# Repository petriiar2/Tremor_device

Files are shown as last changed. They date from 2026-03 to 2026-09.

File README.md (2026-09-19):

# Smart Hand Rehabilitation System — Hardware

> **PCC2 Project | KTH Royal Institute of Technology | MSc Medical Engineering | Stockholm, 2026**  
> *This repository covers only the hardware design, sensor selection, wiring and embedded firmware - the physical core of the system.*
> *Other aspects of the project ( software backend , web application ) are maintained separately and only referenced here for context.*
---

## Table of Contents

- [About the Project](#about-the-project)
- [System Architecture](#system-architecture)
  - [Device Block](#device-block-this-repo)
  - [Computer Block](#computer-block-external-repos)
- [Hardware Design](#hardware-design)
  - [Microcontroller: XIAO Seeed NRF52840](#microcontroller-xiao-seeed-nrf52840)
  - [Sensors](#sensors)
    - [1. Pressure Sensor — ABP-DRRV060MGAA5](#1-pressure-sensor--abp-drrv060mgaa5)
    - [2. EMG Sensor — EMG-LAB](#2-emg-sensor--emg-lab-custom-lab-board)
    - [3. IMU Sensor — LSM6DS3 (on-board NRF52840)](#3-imu-sensor--lsm6ds3-on-board-nrf52840)
  - [Inter-Device Communication](#inter-device-communication)
  - [Design Evolution](#design-evolution)
- [Embedded Firmware](#embedded-firmware)
- [Case Design](#case-design)
- [Device Specifications](#device-specifications)
- [Component List](#component-list)
- [Future Hardware Work](#future-hardware-work)
- [Authors](#authors)
- [License](#license)

## About the Project

Neurological disorders such as stroke, traumatic brain injury, and Parkinson's disease frequently impair hand motor function — manifesting as muscle weakness, tremor, and loss of coordination. Traditional clinical tools like handheld dynamometers capture only peak grip strength, offering an incomplete picture of neuromuscular recovery.

This project is a **low-cost, wearable hand rehabilitation system** that integrates three sensor modalities — pressure, EMG, and IMU — into a portable, Bluetooth-enabled dual-device platform. The system targets two clinical populations:

- **Stroke / Brain Injury** — emphasis on force control assessment (EMG + Pressure)
- **Parkinson's / Tremor-Dominant** — emphasis on movement quality analysis (IMU + Pressure)

The device streams real-time sensor data via Bluetooth Low Energy (BLE) to a companion web application, which guides the patient through rehabilitation exercises, computes clinically meaningful features, and logs sessions for remote clinician review.

> This repository covers the **hardware design**: electrical schematics, sensor integration, embedded firmware, and device prototyping. The web application and signal processing backend are maintained separately and briefly referenced here for context.

---

## System Architecture

The system is split into two main blocks.

### Device Block (this repo)

Two independent wearable units communicate with each other and relay all data to the computer:

```
[Forearm Unit]                         [Wrist Unit]
 ├─ NRF52840 board (Micro 1)            ├─ NRF52840 board (Micro 2)
 ├─ EMG-LAB sensor (analog, 3.3V, D0)   ├─ Pressure sensor ABP-DRRV060MGAA5 (D0)
 ├─ Li-Po 5V battery (JST)              ├─ On-board IMU LSM6DS3 (3-axis accel + gyro)
 └─ USB-B connector (UART TX/RX)        ├─ Li-Po 5V battery (JST)
                                        └─ USB-A connector (UART TX/RX)
                 │                                   │  │
                 └──────────── UART ─────────────────┘  │
                                                        │
                                                   BLE (2.4 GHz)
                                                        │
                                                    [Computer]
```

The forearm unit (Micro 1) collects EMG data, applies preliminary digital filtering on-chip, and forwards the processed samples to the wrist unit over a UART serial link. The wrist unit (Micro 2) acts as the aggregation node — it samples EMG, IMU, and pressure data and transmits everything to the computer over Bluetooth using the Nordic UART Service (NUS).

### Computer Block (external repos)

- **FastAPI backend** — receives BLE data via WebSocket, runs the signal processing and feature extraction pipeline
- **Web application** — real-time sensor visualization, exercise guidance, session logging, and longitudinal progress tracking
- **ML pipeline** — SVM state classifier pre-trained on public datasets + centroid distance longitudinal progress tracker (kNN planned as a later extension)

---

## Hardware Design

### Microcontroller: XIAO Seeed NRF52840

Both units are built around the **NRF52840** board (NRF52 family). Key properties that motivated this choice:

| Feature | Value |
|---|---|
| Processor | 32-bit ARM Cortex-M4 with FPU |
| Clock speed | 64 MHz |
| Flash | 2 MB |
| BLE | Built-in (2.4 GHz) |
| IMU | Built-in LSM6DS3 (3-axis accelerometer + gyroscope) |
| I/O | Digital + analog pins, I²C, UART |
| Power | Onboard Li-Po charging module (5V input via JST) |
| Size | Compact form factor |

All analog signal processing (filtering, ADC) happens directly on the board, eliminating the need for external op-amp circuits. This is a deliberate departure from the original design (see [Design Evolution](#design-evolution) below).

---

### Sensors

#### 1. Pressure Sensor — ABP-DRRV060MGAA5

**Purpose:** Measures grip force during exercises. Connected via a plastic tube to a rubber bulb held in the patient's hand.

| Property | Value |
|---|---|
| Supply voltage | 3.3 V |
| Output | Analog (connected to pin `D0` on wrist unit) |
| Principle | Piezoresistive — silicon diaphragm deforms under pressure, resistance change → analog voltage |
| Placement | On-board the wrist device; tube routed to patient's palm |

**Why this sensor?** A commercial dynamometer capable of real-time wireless data transmission was the original target, but budget constraints led to this pressure sensor solution. Its output voltage scales linearly with applied pressure, so it reliably captures the force waveform over time, enabling extraction of features beyond simple peak force. Unlike a rigid load cell, it integrates into a deformable object that minimizes wrist loading during tremor measurement.

**Signal preprocessing:** Butterworth low-pass filter at 20 Hz cutoff to remove high-frequency noise from hand vibrations. Optional DC baseline correction when the hand is at rest.

**Extracted features:**

| Feature | Formula / Description |
|---|---|
| Maximum Voluntary Contraction (MVC) | Peak force during a maximal squeeze |
| Rate of Force Development (RFD) | `dF/dt` — slope of the force-time curve |
| Fatigue Index | `(F_initial − F_final) / F_initial` |
| Force Variability (CV) | `SD / Mean Force` — coefficient of variation during submaximal holds |
| Tremor amplitude | Force oscillation amplitude during steady holds (Parkinson group) |
| Spectral power in tremor band | PSD integrated over 4–12 Hz |

---

#### 2. EMG Sensor — EMG-LAB (custom lab board)

**Purpose:** Measures electrical activity of the flexor digitorum superficialis muscle to assess neuromuscular activation, fatigue, and tremor modulation.

| Property | Value |
|---|---|
| Supply voltage | 3.3 V |
| Output | Analog (connected to pin `D0` on forearm unit) |
| Electrode configuration | Both measurement electrodes embedded directly on board; virtual ground reference on-board |
| Placement | Inner forearm, fixed with silver chloride gel electrodes |

**Why this sensor?** The previous design used a Muscle Sensor V3.0, which required a ±9 V bipolar supply (two 9 V batteries = 90 g of bulk). The EMG-LAB sensor runs at 3.3 V from the same Li-Po battery powering the board, dramatically reducing weight and complexity.

> ⚠️ The EMG-LAB sensor was borrowed from a previous laboratory project and must be returned after completion. The sensor is mounted in a removable socket soldered onto the forearm PCB.

**Electrode placement:** Electrodes must be aligned along the muscle fibers of the flexor digitorum superficialis, spaced ≤ 2 cm apart. Good-quality silver chloride gel electrodes are required to minimize skin-electrode impedance.

**Signal preprocessing (two-stage pipeline):**

*On-chip (NRF52840, Stage 1):*
- DC offset removal — an exponential moving average estimates and subtracts the DC component to center the signal around zero
- Digital notch filter at 50 Hz — a second-order IIR filter removes power-line interference
- Lightweight IIR band-pass filter (20–450 Hz) — attenuates motion artifacts and high-frequency sensor noise while preserving the physiological EMG band

*Offline in Python (backend, Stage 2):*
- Higher-order Butterworth band-pass 20–450 Hz — sharper cutoff and better stopband attenuation
- Full-wave rectification
- Moving RMS window — generates smooth muscle activation envelope

**Extracted features:**

| Feature | Formula / Description |
|---|---|
| EMG RMS | `sqrt(1/N * Σ e²_i)` — overall muscle activation level |
| Median Frequency Shift | Change in spectral median between first and second half of contraction — fatigue indicator |
| Tremor Band Power | PSD of EMG envelope integrated over 2–12 Hz |
| Peak Tremor Frequency | `argmax PSD` over [2, 12] Hz — identifies dominant tremor frequency |
| Electromechanical Delay (EMD) | `t_force_onset − t_EMG_onset` — neuromuscular transmission efficiency |

---

#### 3. IMU Sensor — LSM6DS3 (on-board NRF52840)

**Purpose:** Measures linear acceleration and angular velocity in 3 axes to quantify hand tremor, orientation stability, and movement quality.

| Property | Value |
|---|---|
| Model | LSM6DS3 (integrated on the NRF52840 board) |
| Type | 3-axis accelerometer + 3-axis gyroscope (MEMS) |
| Interface | I²C at address `0x6A` |
| Configuration | ±2 g accelerometer, ±250 °/s gyroscope, 104 Hz ODR (decimated to 25 Hz) |
| Supply | Powered by the NRF52840 board (no extra wiring) |
| Placement | Wrist unit, outer side of the hand |

**Signal preprocessing:**
- Butterworth low-pass filter at 20 Hz cutoff (accelerometer + gyroscope)
- Sensor fusion (accelerometer + gyroscope) for accurate orientation estimation and drift reduction
- FFT / PSD for frequency-domain tremor analysis

**Clinically relevant frequency bands:**

| Band | Range | Meaning |
|---|---|---|
| Physiological tremor | 8–12 Hz | Normal, non-pathological oscillations |
| Parkinson's rest tremor | 4–6 Hz | Pathological resting tremor |
| Essential tremor | 5–12 Hz | Postural or action tremor |
| Voluntary / postural | < 4 Hz | Excluded from tremor analysis |

**Extracted features:**

| Feature | Formula / Description |
|---|---|
| Tremor Power (4–12 Hz) | `Σ PSD(a_mag)` over 4–12 Hz |
| Tremor Frequency | `argmax PSD(a_mag)` over [4, 12] Hz |
| Orientation Stability | `Var(θ)` during hold phase |
| Range of Motion (ROM) | `θ_max − θ_min` during grip/dynamic tasks |
| Hold Stability | `SD(ω_mag)` during plateau phase |
| Drift Rate | `(θ_end − θ_start) / t_hold` |

---

### Inter-Device Communication

The two boards communicate via **UART** over pins `D6`–`D7` at 115200 baud, routed through an external USB cable (USB-A on the wrist unit, USB-B on the forearm unit). UART was chosen because it is a digital interface — it introduces zero noise into the data, and all analog signal paths are kept as short as possible within each unit.

The forearm unit (Micro 1) transmits each filtered EMG value to the wrist unit in the ASCII format `E,<value>\n`. Its BLE radio remains disabled to conserve power.

Bluetooth transmission is intentionally implemented only from the **wrist unit** (Micro 2) to minimize electromagnetic interference with the sensitive EMG module on the forearm unit. Two interference mechanisms were identified and mitigated:

1. The BLE 2.4 GHz carrier — kept physically separated from the EMG analog path
2. Uneven BLE power consumption — current spikes during active transmission can cause voltage supply fluctuations that corrupt EMG readings

---

### Design Evolution

#### Why Moved Away from the Original Design

> The old single-unit schematic is preserved for reference:
<p align="center">
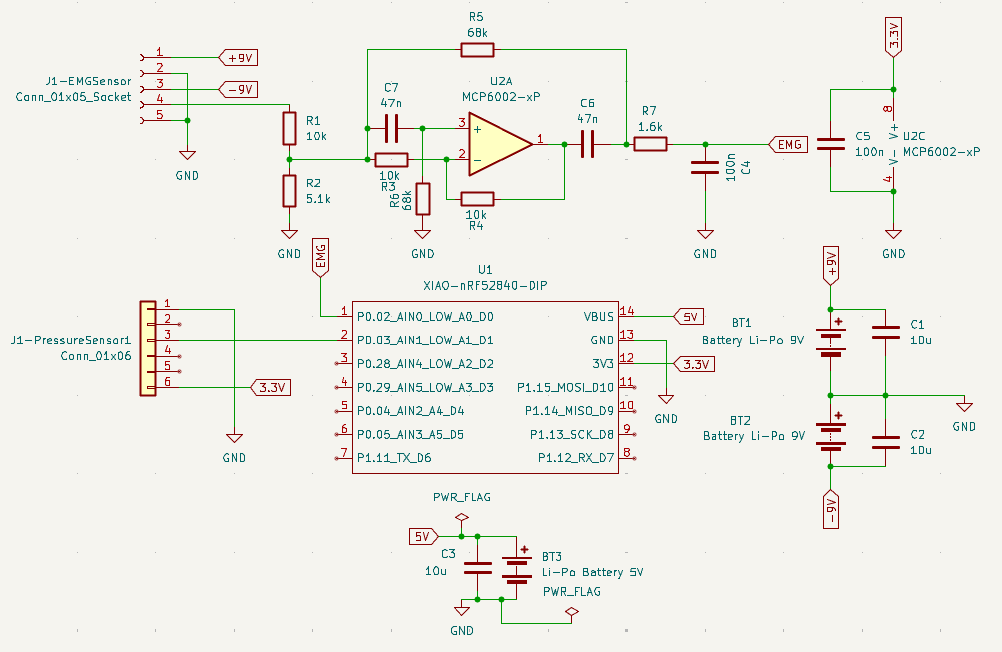
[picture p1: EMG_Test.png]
  
</p>

The first prototype used a **Muscle Sensor V3.0** EMG sensor with an analog filter cascade (band-stop at 50 Hz + low-pass at 1000 Hz). The original single-unit board integrated all sensors (pressure, EMG, IMU) on one wrist-worn device powered by two 9 V batteries. Two critical problems emerged:

**Battery problem:** The Muscle Sensor V3.0 requires a ±9 V bipolar supply. Generating this from two 9 V batteries (each 45 g) mounted on the wrist added significant mass — enough to mechanically affect tremor measurements and distort baseline muscle load:

```
Greater load → higher permanent muscle strain → signal offset relative to unloaded baseline
```

Because the NRF52 board accepts a maximum of 3.3 V on its pins, the bipolar supply was stepped down with a voltage divider (`R1 = 10 kΩ`, `R2 = 5.1 kΩ` → ≈ 3.04 V). A band-stop filter (MCP6002 op-amp, `C7 = 47 nF`, `R6 = 68 kΩ`) targeted 50 Hz mains (≈ 49.7 Hz), and a low-pass stage (`R7 = 1.6 kΩ`, `C = 100 nF`) cut noise above ≈ 995 Hz.

**Analog filtering problem:** Component availability in the lab was limited; the exact resistor-capacitor values for the target filter frequencies were not always obtainable. Compromise values resulted in poorly attenuated noise, requiring additional digital post-processing anyway. Since digital filtering on the NRF52840 is more precise and flexible than any analog cascade achievable with available parts, analog filtering was abandoned entirely.

#### Current Design Improvements

<p align="center">
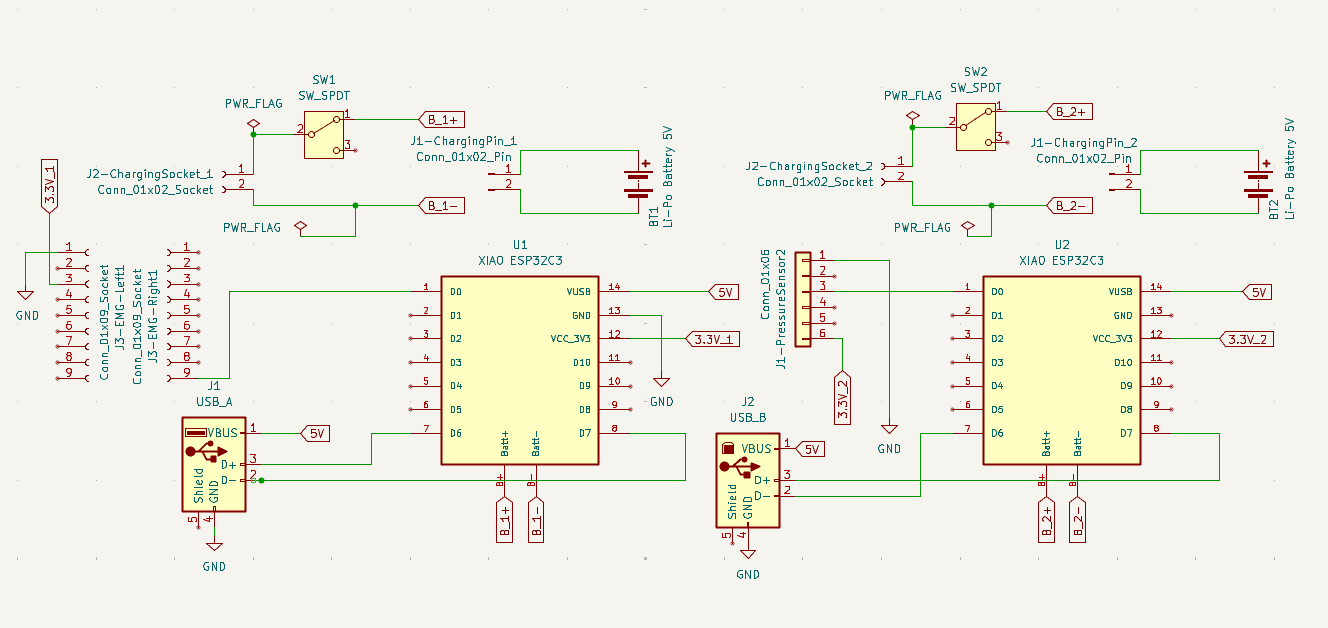
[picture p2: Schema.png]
  
</p>

The new EMG-LAB sensor has both electrodes embedded directly on the board. To minimize wire length between the sensor and the microcontroller (reducing noise), the board and sensor are placed on the inner forearm. Since tremor must still be measured at the wrist, the original single device was split into two independent units: one on the wrist and one on the inner forearm.

| Aspect | Old Design | Current Design |
|---|---|---|
| EMG sensor | Muscle Sensor V3.0 | EMG-LAB (3.3V, on-board electrodes) |
| Power supply | 2× 9V batteries (90g) | 2× Li-Po 5V (10g each) |
| Analog filtering | Band-stop + low-pass RC circuits | Removed — fully digital |
| Physical form | Single unit on wrist | Two units: forearm (EMG) + wrist (IMU/Pressure) |
| Weight (forearm) | — | 21 g (27 g with battery) |
| Weight (wrist) | — | 16 g (35 g with battery) |
| IMU placement | Wrist | Wrist (enables future forearm tremor localization) |

The two boards each have their own 5 V Li-Po battery on a 2-pin JST connector, so every unit operates fully independently, both operationally and energetically. Dedicated slide switches allow each device to be turned on independently and shut down in a controlled manner.

PCBs were designed for both devices according to the tested prototypes and their circuits. Due to the limited budget and capabilities of the university equipment, PCB fabrication was abandoned in favor of perfboard prototypes trimmed to fit the components — but the completed board designs are documented here as the intended production form.

**PCB layouts (2D):**
<p align="center">
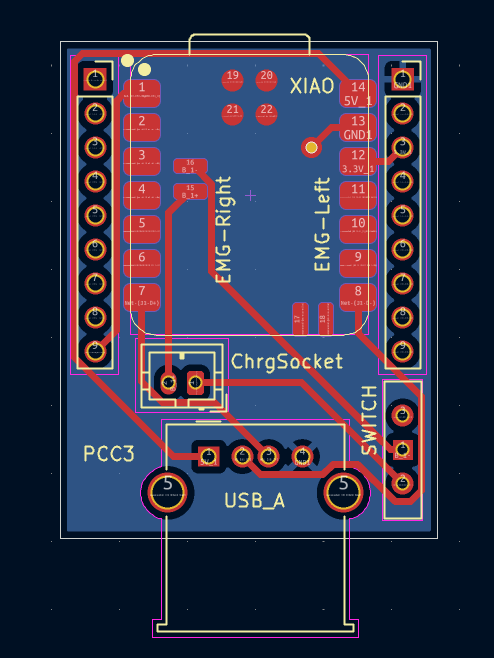
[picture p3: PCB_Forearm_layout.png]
  
  &nbsp;
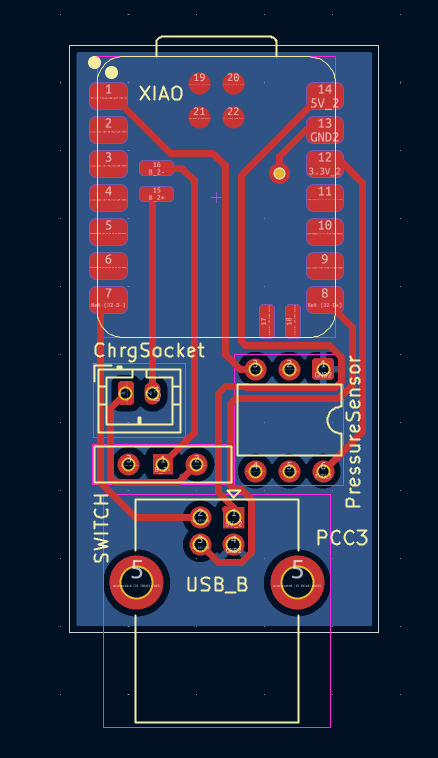
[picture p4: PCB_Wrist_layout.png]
  
</p>
<p align="center"><i>(left) Forearm device — EMG sensor board &nbsp;•&nbsp; (right) Wrist device — pressure sensor board</i></p>

**PCB 3D renders:**
<p align="center">
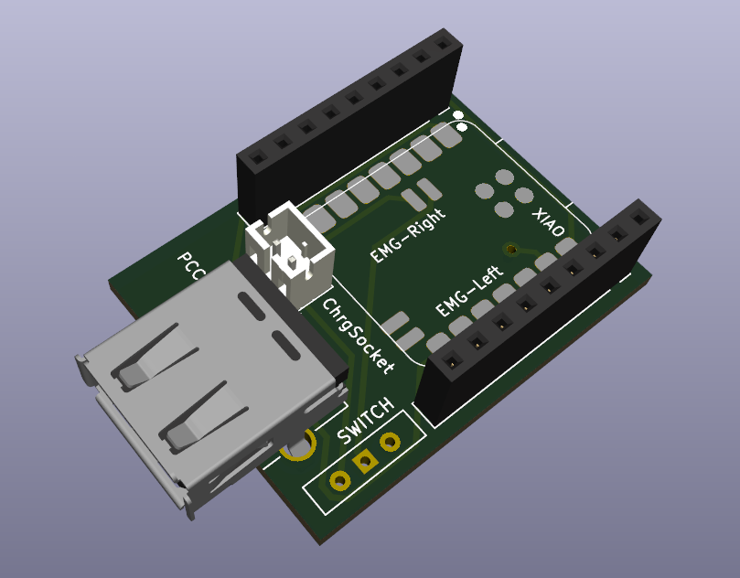
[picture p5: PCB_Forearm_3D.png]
  
  &nbsp;
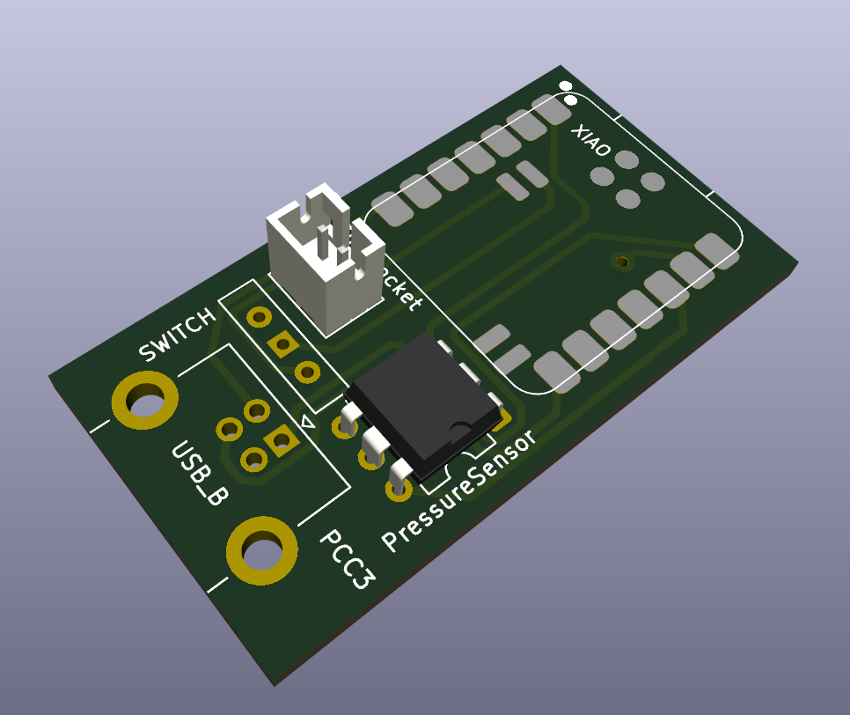
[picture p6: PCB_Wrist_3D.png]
  
</p>
<p align="center"><i>(left) Forearm device 3D view &nbsp;•&nbsp; (right) Wrist device 3D view</i></p>

Image of the forearm device
<p align="center">
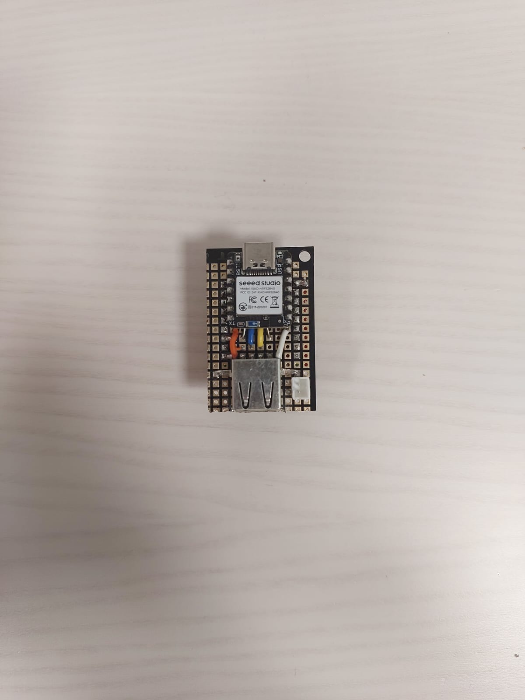
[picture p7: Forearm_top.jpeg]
  
  &nbsp;
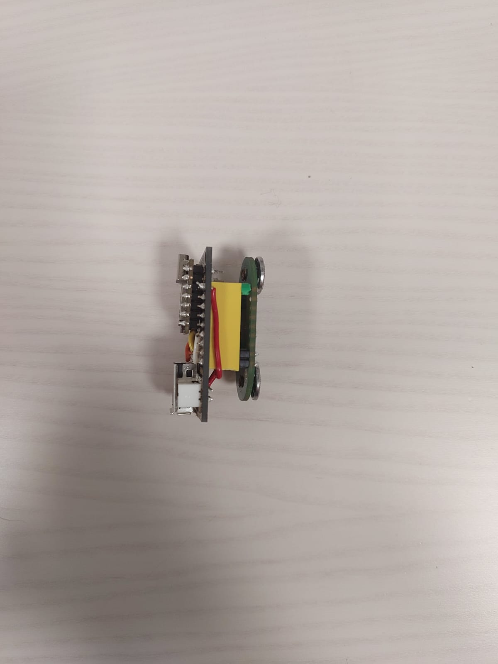
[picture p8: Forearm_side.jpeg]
  
</p>

Image of the wrist device and the general view of the system
<p align="center">
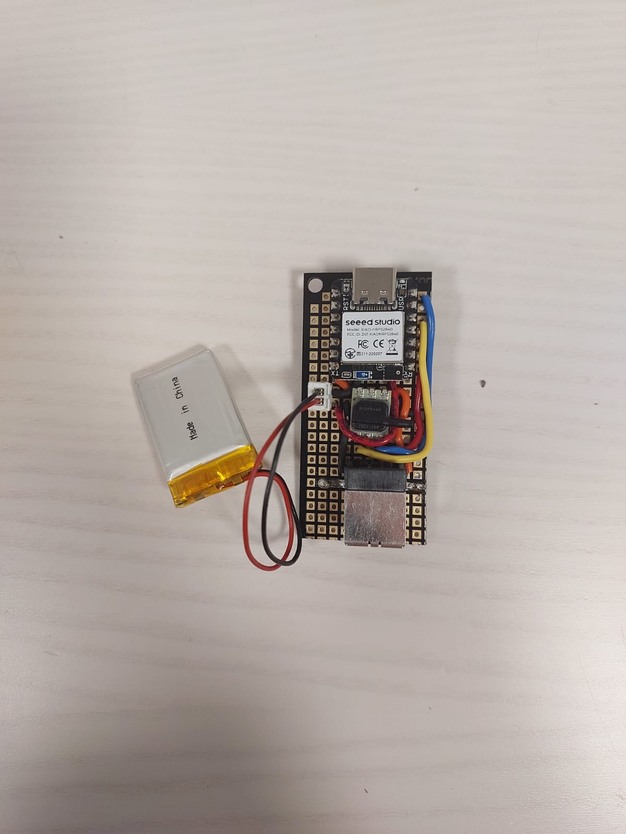
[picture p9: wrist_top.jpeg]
  
  &nbsp;
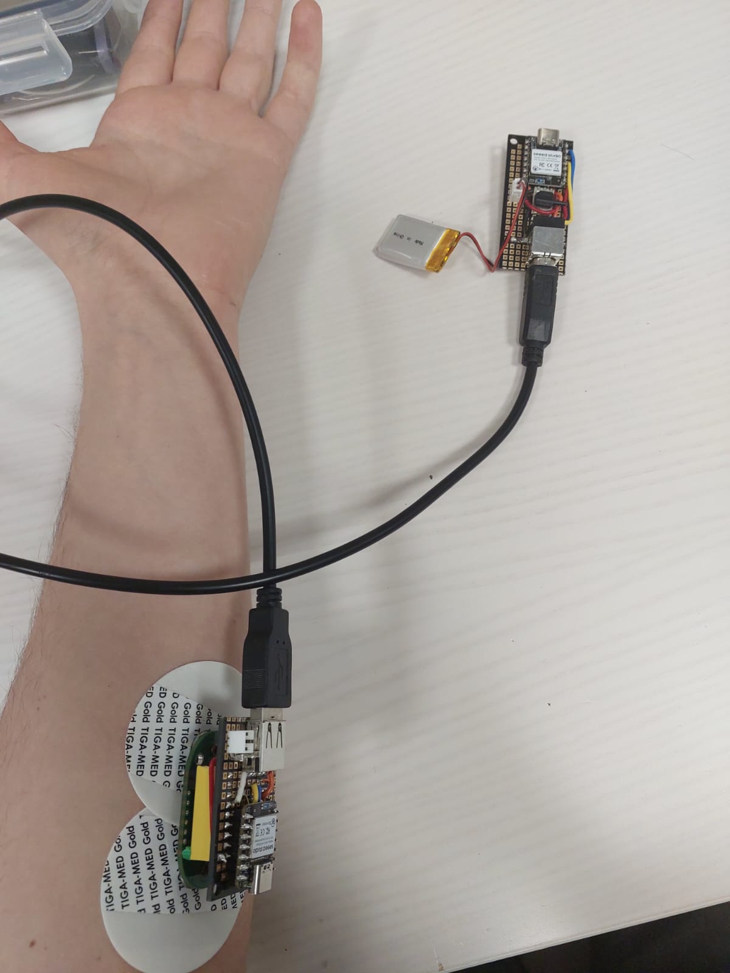
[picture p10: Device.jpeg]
  
</p>

---

## Embedded Firmware

Both microcontrollers run identical **40 ms timing loops**, giving a system-wide sampling rate of **25 Hz**. This rate provides a ~56% margin above the Nyquist minimum for the 4–12 Hz tremor band, lets the frame fit within the negotiated BLE MTU, and allows the MCU to deep-sleep between transmissions (battery life > 8 h continuous).

**Micro 1 (forearm — EMG):** samples EMG at 25 Hz, runs the on-device two-stage preprocessing (DC offset removal + 50 Hz IIR notch + 20–450 Hz band-pass), and pushes each value over UART.

**Micro 2 (wrist — aggregation + BLE):** three concurrent tasks —
- **Pressure:** 12-bit ADC reading (0–4095) from `D0`, normalized to 8-bit (÷16)
- **IMU:** LSM6DS3 over I²C `0x6A`, `CTRL1_XL`/`CTRL2_G = 0x60`, decimated to 25 Hz
- **EMG reception:** character-by-character UART parser on the `E,<value>\n` stream

Every 40 ms the aggregated values are packed into a single comma-separated ASCII frame and sent via the Nordic UART Service (NUS):

```
F,<frame_id>,<pressure>,<emg>,<ax>,<ay>,<az>,<gx>,<gy>,<gz>\n
```

Frames are ~35–40 bytes. Integrity is checked by counting comma separators (9 expected); malformed frames are discarded. A **247-byte MTU** is requested at connection so the full frame fits in one BLE packet without fragmentation, though the system still works if a lower MTU is negotiated. Transmission is fire-and-forget (no retransmission); frame-ID gaps flag packet loss, which stays under 1% and does not affect clinical assessment.

---

## Case Design

A protective case is required for safe patient use: it must isolate the patient from the circuit elements and hold the board and battery cells together as one unit. Given the constraints of the available tools and 3D printer, each case is built around a **rigid printed substrate**, complemented by a soft outer layer:

- **Forearm (arm) device** — the rigid substrate is paired with a soft-plastic cover of a similar shape.
- **Wrist device** — the rigid substrate is fixed inside a sports band through purpose-designed eyelets.

**Case substrates (3D design):**
<p align="center">
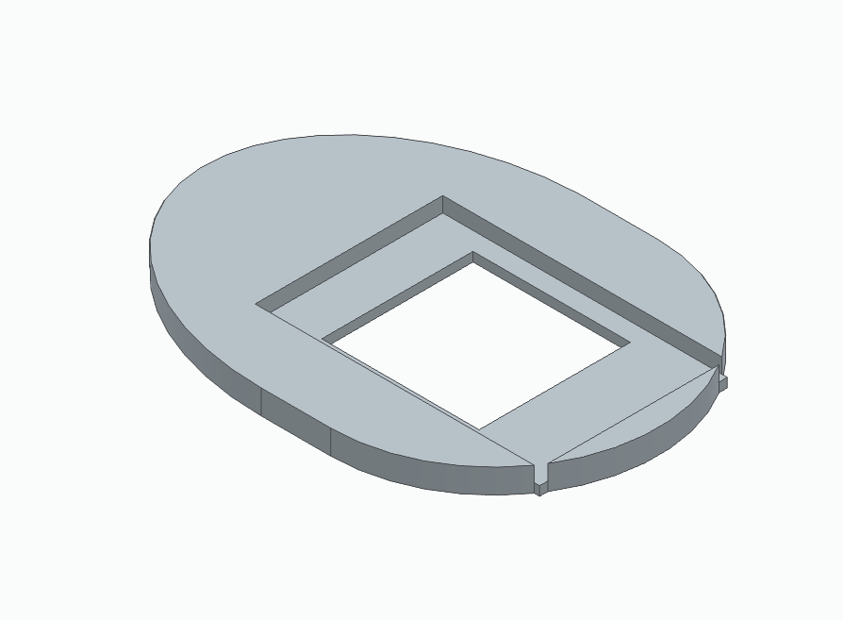
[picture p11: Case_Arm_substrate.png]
  
  &nbsp;
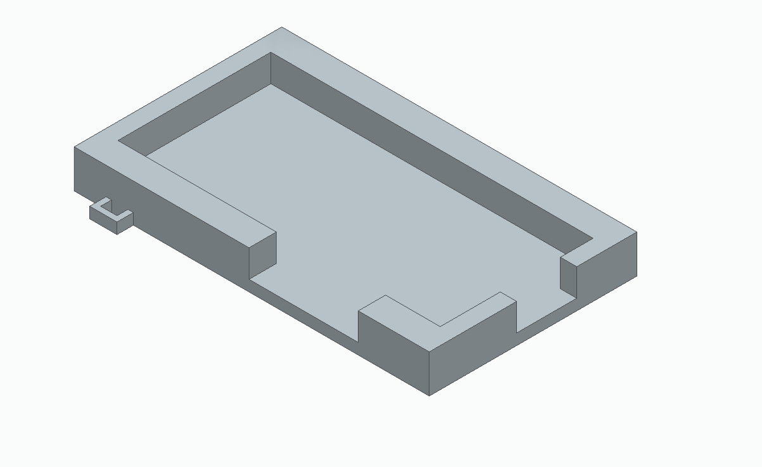
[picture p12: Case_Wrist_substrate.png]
  
</p>
<p align="center"><i>(left) Arm device substrate &nbsp;•&nbsp; (right) Wrist device substrate</i></p>

**Assembled devices in their cases:**
<p align="center">
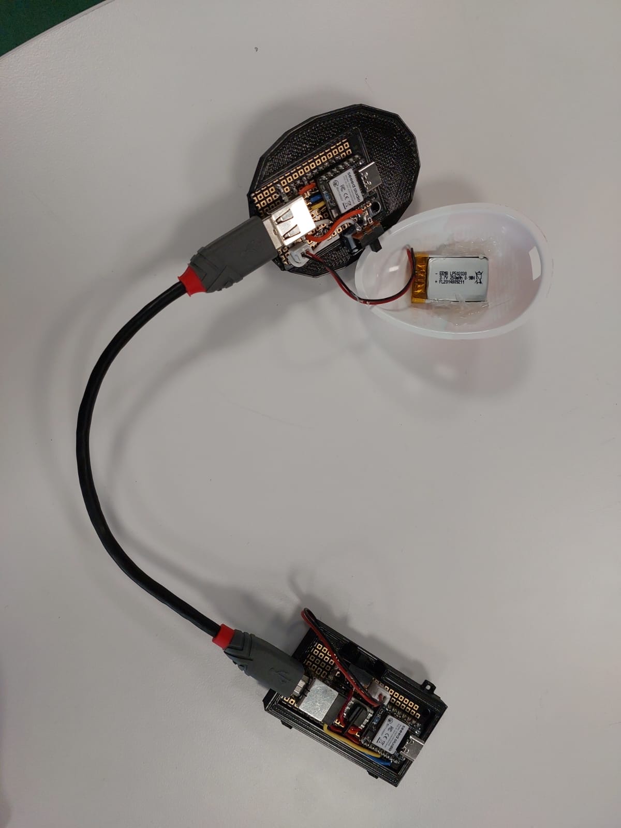
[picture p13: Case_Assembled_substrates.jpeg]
  
  &nbsp;
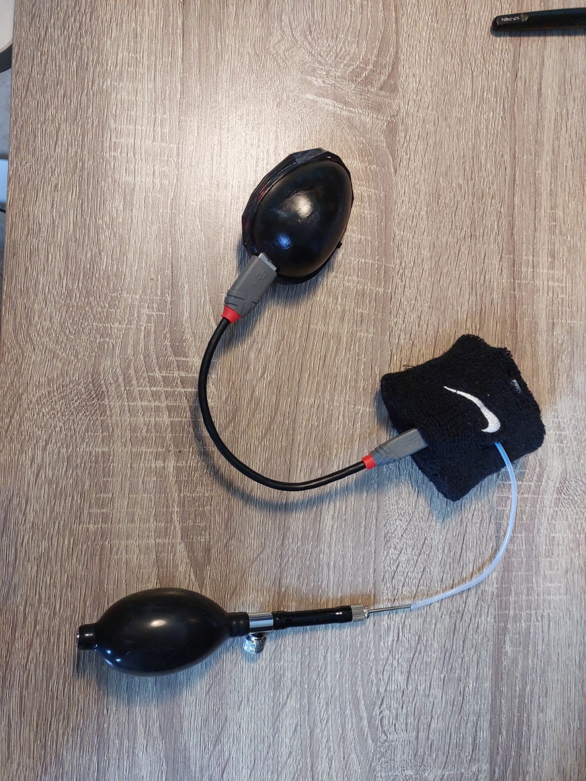
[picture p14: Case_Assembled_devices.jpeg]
  
</p>
<p align="center"><i>(left) Assembled substrates &nbsp;•&nbsp; (right) Fully assembled devices with bulb and strap</i></p>

**Device in use:**
<p align="center">
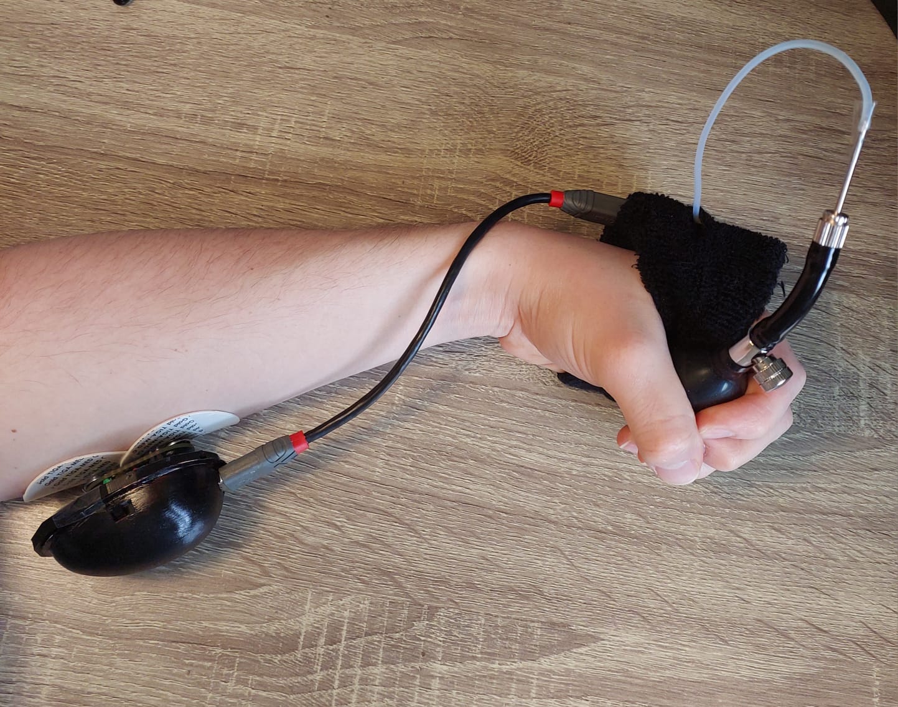
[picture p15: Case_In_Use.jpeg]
  
</p>
<p align="center"><i>General view of the system worn on the hand and forearm</i></p>

**Known limitations of the current case:**
- The university printer could not produce the complex mechanical elements originally planned to hold the arm-device cap, so those were dropped.
- The main fasteners are currently weakly adhesive elements, which do not provide a sufficiently stable fit. Stronger *permanent* fastening is not acceptable, because the device must remain accessible for programming and configuration — a removable but firmer mechanism is needed.
- The EMG-sensor clip mechanism is particularly weak; its fastenings have loosened through wear, and since the sensor is on loan it cannot be permanently re-fitted.

---

## Device Specifications

### Forearm Unit
- **Weight:** 21 g (27 g including battery)
- **Dimensions:** 3.0 × 4.6 × 2.2 cm
- **Mounting:** Silver chloride gel electrodes adhered directly to the inner forearm skin
- **Battery:** 300 mAh Li-Po, 3.7–5 V, rechargeable via JST connector

### Wrist Unit
- **Weight:** 16 g (35 g including battery)
- **Dimensions:** 2.7 × 5.8 × 1.4 cm
- **Mounting:** Sports fabric strap on the outer wrist
- **Battery:** 300 mAh Li-Po, 3.7–5 V, rechargeable via JST connector

> For reference, a single 9 V battery weighs 45 g — illustrating the significant weight reduction achieved by moving to compact Li-Po cells.

---

## Component List

| Component | Model / Type | Role |
|---|---|---|
| Main board ×2 | NRF52840 (NRF52 family) | Core controller, BLE, IMU |
| IMU | LSM6DS3 (on-board, 3-axis accel + gyro) | Motion and tremor sensing |
| Pressure sensor | ABP-DRRV060MGAA5 | Grip force measurement |
| EMG sensor | EMG-LAB (lab-sourced) | Muscle activation measurement |
| Forearm connector | USB-B (4-pin) | UART inter-device link |
| Wrist connector | USB-A (4-pin) | UART inter-device link |
| Batteries ×2 | 3.7–5 V Li-Po, 300 mAh | Board power supply |
| Electrode pads | Silver chloride gel | EMG signal acquisition |

---

## Future Hardware Work

**Enclosure & mechanical**
- **Stronger case fastening:** replace the weak adhesive fasteners with a firmer *removable* mechanism (e.g. clothespin-style clips) or use more advanced printing methods, while keeping the device accessible for programming and configuration.
- **EMG sensor clip:** the borrowed EMG-LAB mounting clip has loosened with wear and needs a proper replacement holder.
- **Manufactured PCBs:** fabricate the documented board designs instead of perfboard prototypes once budget/equipment allow.

**Power**
- **Power switch:** slide switches are present per unit; a unified power scheme is desirable.
- **Unified charging:** single charging port / switch for both units instead of two separate JST connectors.

**Sensing**
- **Extended sensor coverage:** additional IMU unit on the forearm to localize tremor by segment.
- **Analog filter revisit:** at a later stage, when minimizing acquisition latency becomes critical, a minimal analog pre-filter stage may be reintroduced.

---

## Authors

This project was developed as part of a university course project.

- **Iaroslav Petrishchev** — Hardware design, electrical schematics, component selection and procurement, device assembly and testing, case design *(this repository)*
- **Naya Nasr** [LinkedIn](https://www.linkedin.com/in/nasrnaya/)  — NRF52 sensor programming, data acquisition firmware, web application, machine learning pipeline
- **Lucía Pérez Sáez** [LinkedIn]( https://www.linkedin.com/in/lucia-perez-saez/)  — Exercise protocols, signal processing design, backend integration, FSM and WebSocket logic

---

## License

To be determined.

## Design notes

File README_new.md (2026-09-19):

# Smart Hand Rehabilitation System — Hardware

> ⚠️ **This repository is under active development.** Hardware schematics, firmware code, and documentation will be updated continuously as the project evolves.
> 
> **PCC2 Project | KTH Royal Institute of Technology | MSc Medical Engineering | Stockholm, 2026**  
> *This repository covers only the hardware design, sensor selection, wiring and embedded firmware - the physical core of the system.*
> *Other aspects of the project ( software backend , web application ) are maintained separately and only referenced here for context.*
---

## Table of Contents

- [About the Project](#about-the-project)
- [System Architecture](#system-architecture)
  - [Device Block](#device-block-this-repo)
  - [Computer Block](#computer-block-external-repos)
- [Hardware Design](#hardware-design)
  - [Microcontroller: XIAO Seeed NRF52840](#microcontroller-xiao-seeed-nrf52840)
- [Sensors](#sensors)
  - [1. Pressure Sensor — ABP-DRRV060MGAA5](#1-pressure-sensor--abp-drrv060mgaa5)
  - [2. EMG Sensor — EMG-LAB](#2-emg-sensor--emg-lab-custom-lab-board)
  - [3. IMU Sensor — LSM6DS3 (on-board NRF52840)](#3-imu-sensor--lsm6ds3-on-board-nrf52840)
- [Inter-Device Communication](#inter-device-communication)
- [Embedded Firmware](#embedded-firmware)
- [Design Evolution](#design-evolution)
- [Device Specifications](#device-specifications)
- [Component List](#component-list)
- [Future Hardware Work](#future-hardware-work)
- [Authors](#authors)
- [License](#license)

## About the Project

Neurological disorders such as stroke, traumatic brain injury, and Parkinson's disease frequently impair hand motor function — manifesting as muscle weakness, tremor, and loss of coordination. Traditional clinical tools like handheld dynamometers capture only peak grip strength, offering an incomplete picture of neuromuscular recovery.

This project is a **low-cost, wearable hand rehabilitation system** that integrates three sensor modalities — pressure, EMG, and IMU — into a portable, Bluetooth-enabled dual-device platform. The system targets two clinical populations:

- **Stroke / Brain Injury** — emphasis on force control assessment (EMG + Pressure)
- **Parkinson's / Tremor-Dominant** — emphasis on movement quality analysis (IMU + Pressure)

The device streams real-time sensor data via Bluetooth Low Energy (BLE) to a companion web application, which guides the patient through rehabilitation exercises, computes clinically meaningful features, and logs sessions for remote clinician review.

> This repository covers the **hardware design**: electrical schematics, sensor integration, embedded firmware, and device prototyping. The web application and signal processing backend are maintained separately and briefly referenced here for context.

---

## System Architecture

The system is split into two main blocks.

### Device Block (this repo)

Two independent wearable units communicate with each other and relay all data to the computer:

```
[Forearm Unit]                         [Wrist Unit]
 ├─ NRF52840 board (Micro 1)            ├─ NRF52840 board (Micro 2)
 ├─ EMG-LAB sensor (analog, 3.3V, D0)   ├─ Pressure sensor ABP-DRRV060MGAA5 (D0)
 ├─ Li-Po 5V battery (JST)              ├─ On-board IMU LSM6DS3 (3-axis accel + gyro)
 └─ USB-B connector (UART TX/RX)        ├─ Li-Po 5V battery (JST)
                                        └─ USB-A connector (UART TX/RX)
                 │                                   │  │
                 └──────────── UART ─────────────────┘  │
                                                        │
                                                   BLE (2.4 GHz)
                                                        │
                                                    [Computer]
```

The forearm unit (Micro 1) collects EMG data, applies preliminary digital filtering on-chip, and forwards the processed samples to the wrist unit over a UART serial link. The wrist unit (Micro 2) acts as the aggregation node — it samples EMG, IMU, and pressure data and transmits everything to the computer over Bluetooth using the Nordic UART Service (NUS).

### Computer Block (external repos)

- **FastAPI backend** — receives BLE data via WebSocket, runs the signal processing and feature extraction pipeline
- **Web application** — real-time sensor visualization, exercise guidance, session logging, and longitudinal progress tracking
- **ML pipeline** — SVM state classifier pre-trained on public datasets + centroid distance longitudinal progress tracker (kNN planned as a later extension)

---

## Hardware Design

### Microcontroller: XIAO Seeed NRF52840

Both units are built around the **NRF52840** board (NRF52 family). Key properties that motivated this choice:

| Feature | Value |
|---|---|
| Processor | 32-bit ARM Cortex-M4 with FPU |
| Clock speed | 64 MHz |
| Flash | 2 MB |
| BLE | Built-in (2.4 GHz) |
| IMU | Built-in LSM6DS3 (3-axis accelerometer + gyroscope) |
| I/O | Digital + analog pins, I²C, UART |
| Power | Onboard Li-Po charging module (5V input via JST) |
| Size | Compact form factor |

All analog signal processing (filtering, ADC) happens directly on the board, eliminating the need for external op-amp circuits. This is a deliberate departure from the original design (see [Design Evolution](#design-evolution) below).

---

## Sensors

### 1. Pressure Sensor — ABP-DRRV060MGAA5

**Purpose:** Measures grip force during exercises. Connected via a plastic tube to a rubber bulb held in the patient's hand.

| Property | Value |
|---|---|
| Supply voltage | 3.3 V |
| Output | Analog (connected to pin `D0` on wrist unit) |
| Principle | Piezoresistive — silicon diaphragm deforms under pressure, resistance change → analog voltage |
| Placement | On-board the wrist device; tube routed to patient's palm |

**Why this sensor?** A commercial dynamometer capable of real-time wireless data transmission was the original target, but budget constraints led to this pressure sensor solution. Its output voltage scales linearly with applied pressure, so it reliably captures the force waveform over time, enabling extraction of features beyond simple peak force. Unlike a rigid load cell, it integrates into a deformable object that minimizes wrist loading during tremor measurement.

**Signal preprocessing:** Butterworth low-pass filter at 20 Hz cutoff to remove high-frequency noise from hand vibrations. Optional DC baseline correction when the hand is at rest.

**Extracted features:**

| Feature | Formula / Description |
|---|---|
| Maximum Voluntary Contraction (MVC) | Peak force during a maximal squeeze |
| Rate of Force Development (RFD) | `dF/dt` — slope of the force-time curve |
| Fatigue Index | `(F_initial − F_final) / F_initial` |
| Force Variability (CV) | `SD / Mean Force` — coefficient of variation during submaximal holds |
| Tremor amplitude | Force oscillation amplitude during steady holds (Parkinson group) |
| Spectral power in tremor band | PSD integrated over 4–12 Hz |

---

### 2. EMG Sensor — EMG-LAB (custom lab board)

**Purpose:** Measures electrical activity of the flexor digitorum superficialis muscle to assess neuromuscular activation, fatigue, and tremor modulation.

| Property | Value |
|---|---|
| Supply voltage | 3.3 V |
| Output | Analog (connected to pin `D0` on forearm unit) |
| Electrode configuration | Both measurement electrodes embedded directly on board; virtual ground reference on-board |
| Placement | Inner forearm, fixed with silver chloride gel electrodes |

**Why this sensor?** The previous design used a Muscle Sensor V3.0, which required a ±9 V bipolar supply (two 9 V batteries = 90 g of bulk). The EMG-LAB sensor runs at 3.3 V from the same Li-Po battery powering the board, dramatically reducing weight and complexity.

> ⚠️ The EMG-LAB sensor was borrowed from a previous laboratory project and must be returned after completion. The sensor is mounted in a removable socket soldered onto the forearm PCB.

**Electrode placement:** Electrodes must be aligned along the muscle fibers of the flexor digitorum superficialis, spaced ≤ 2 cm apart. Good-quality silver chloride gel electrodes are required to minimize skin-electrode impedance.

**Signal preprocessing (two-stage pipeline):**

*On-chip (NRF52840, Stage 1):*
- DC offset removal — an exponential moving average estimates and subtracts the DC component to center the signal around zero
- Digital notch filter at 50 Hz — a second-order IIR filter removes power-line interference
- Lightweight IIR band-pass filter (20–450 Hz) — attenuates motion artifacts and high-frequency sensor noise while preserving the physiological EMG band

*Offline in Python (backend, Stage 2):*
- Higher-order Butterworth band-pass 20–450 Hz — sharper cutoff and better stopband attenuation
- Full-wave rectification
- Moving RMS window — generates smooth muscle activation envelope

**Extracted features:**

| Feature | Formula / Description |
|---|---|
| EMG RMS | `sqrt(1/N * Σ e²_i)` — overall muscle activation level |
| Median Frequency Shift | Change in spectral median between first and second half of contraction — fatigue indicator |
| Tremor Band Power | PSD of EMG envelope integrated over 2–12 Hz |
| Peak Tremor Frequency | `argmax PSD` over [2, 12] Hz — identifies dominant tremor frequency |
| Electromechanical Delay (EMD) | `t_force_onset − t_EMG_onset` — neuromuscular transmission efficiency |

---

### 3. IMU Sensor — LSM6DS3 (on-board NRF52840)

**Purpose:** Measures linear acceleration and angular velocity in 3 axes to quantify hand tremor, orientation stability, and movement quality.

| Property | Value |
|---|---|
| Model | LSM6DS3 (integrated on the NRF52840 board) |
| Type | 3-axis accelerometer + 3-axis gyroscope (MEMS) |
| Interface | I²C at address `0x6A` |
| Configuration | ±2 g accelerometer, ±250 °/s gyroscope, 104 Hz ODR (decimated to 25 Hz) |
| Supply | Powered by the NRF52840 board (no extra wiring) |
| Placement | Wrist unit, outer side of the hand |

**Signal preprocessing:**
- Butterworth low-pass filter at 20 Hz cutoff (accelerometer + gyroscope)
- Sensor fusion (accelerometer + gyroscope) for accurate orientation estimation and drift reduction
- FFT / PSD for frequency-domain tremor analysis

**Clinically relevant frequency bands:**

| Band | Range | Meaning |
|---|---|---|
| Physiological tremor | 8–12 Hz | Normal, non-pathological oscillations |
| Parkinson's rest tremor | 4–6 Hz | Pathological resting tremor |
| Essential tremor | 5–12 Hz | Postural or action tremor |
| Voluntary / postural | < 4 Hz | Excluded from tremor analysis |

**Extracted features:**

| Feature | Formula / Description |
|---|---|
| Tremor Power (4–12 Hz) | `Σ PSD(a_mag)` over 4–12 Hz |
| Tremor Frequency | `argmax PSD(a_mag)` over [4, 12] Hz |
| Orientation Stability | `Var(θ)` during hold phase |
| Range of Motion (ROM) | `θ_max − θ_min` during grip/dynamic tasks |
| Hold Stability | `SD(ω_mag)` during plateau phase |
| Drift Rate | `(θ_end − θ_start) / t_hold` |

---

## Inter-Device Communication

The two boards communicate via **UART** over pins `D6`–`D7` at 115200 baud, routed through an external USB cable (USB-A on the wrist unit, USB-B on the forearm unit). UART was chosen because it is a digital interface — it introduces zero noise into the data, and all analog signal paths are kept as short as possible within each unit.

The forearm unit (Micro 1) transmits each filtered EMG value to the wrist unit in the ASCII format `E,<value>\n`. Its BLE radio remains disabled to conserve power.

Bluetooth transmission is intentionally implemented only from the **wrist unit** (Micro 2) to minimize electromagnetic interference with the sensitive EMG module on the forearm unit. Two interference mechanisms were identified and mitigated:

1. The BLE 2.4 GHz carrier — kept physically separated from the EMG analog path
2. Uneven BLE power consumption — current spikes during active transmission can cause voltage supply fluctuations that corrupt EMG readings

---

## Embedded Firmware

Both microcontrollers run identical **40 ms timing loops**, giving a system-wide sampling rate of **25 Hz**. This rate provides a ~56% margin above the Nyquist minimum for the 4–12 Hz tremor band, lets the frame fit within the negotiated BLE MTU, and allows the MCU to deep-sleep between transmissions (battery life > 8 h continuous).

**Micro 1 (forearm — EMG):** samples EMG at 25 Hz, runs the on-device two-stage preprocessing (DC offset removal + 50 Hz IIR notch + 20–450 Hz band-pass), and pushes each value over UART.

**Micro 2 (wrist — aggregation + BLE):** three concurrent tasks —
- **Pressure:** 12-bit ADC reading (0–4095) from `D0`, normalized to 8-bit (÷16)
- **IMU:** LSM6DS3 over I²C `0x6A`, `CTRL1_XL`/`CTRL2_G = 0x60`, decimated to 25 Hz
- **EMG reception:** character-by-character UART parser on the `E,<value>\n` stream

Every 40 ms the aggregated values are packed into a single comma-separated ASCII frame and sent via the Nordic UART Service (NUS):

```
F,<frame_id>,<pressure>,<emg>,<ax>,<ay>,<az>,<gx>,<gy>,<gz>\n
```

Frames are ~35–40 bytes. Integrity is checked by counting comma separators (9 expected); malformed frames are discarded. A **247-byte MTU** is requested at connection so the full frame fits in one BLE packet without fragmentation, though the system still works if a lower MTU is negotiated. Transmission is fire-and-forget (no retransmission); frame-ID gaps flag packet loss, which stays under 1% and does not affect clinical assessment.

---

## Design Evolution

### Why We Moved Away from the Original Design

<p align="center">
  
</p>

The first prototype used a **Muscle Sensor V3.0** EMG sensor with an analog filter cascade (band-stop at 50 Hz + low-pass at 1000 Hz). The original single-unit board integrated all sensors (pressure, EMG, IMU) on one wrist-worn device powered by two 9 V batteries. Two critical problems emerged:

**Battery problem:** The Muscle Sensor V3.0 requires a ±9 V bipolar supply. Generating this from two 9 V batteries (each 45 g) mounted on the wrist added significant mass — enough to mechanically affect tremor measurements and distort baseline muscle load:

```
Greater load → higher permanent muscle strain → signal offset relative to unloaded baseline
```

Because the NRF52 board accepts a maximum of 3.3 V on its pins, the bipolar supply was stepped down with a voltage divider (`R1 = 10 kΩ`, `R2 = 5.1 kΩ` → ≈ 3.04 V). A band-stop filter (MCP6002 op-amp, `C7 = 47 nF`, `R6 = 68 kΩ`) targeted 50 Hz mains (≈ 49.7 Hz), and a low-pass stage (`R7 = 1.6 kΩ`, `C = 100 nF`) cut noise above ≈ 995 Hz.

**Analog filtering problem:** Component availability in the lab was limited; the exact resistor-capacitor values for the target filter frequencies were not always obtainable. Compromise values resulted in poorly attenuated noise, requiring additional digital post-processing anyway. Since digital filtering on the NRF52840 is more precise and flexible than any analog cascade achievable with available parts, analog filtering was abandoned entirely.

> The old single-unit schematic is preserved for reference:
> <p align="center">
>   
> </p>

### Current Design Improvements

<p align="center">
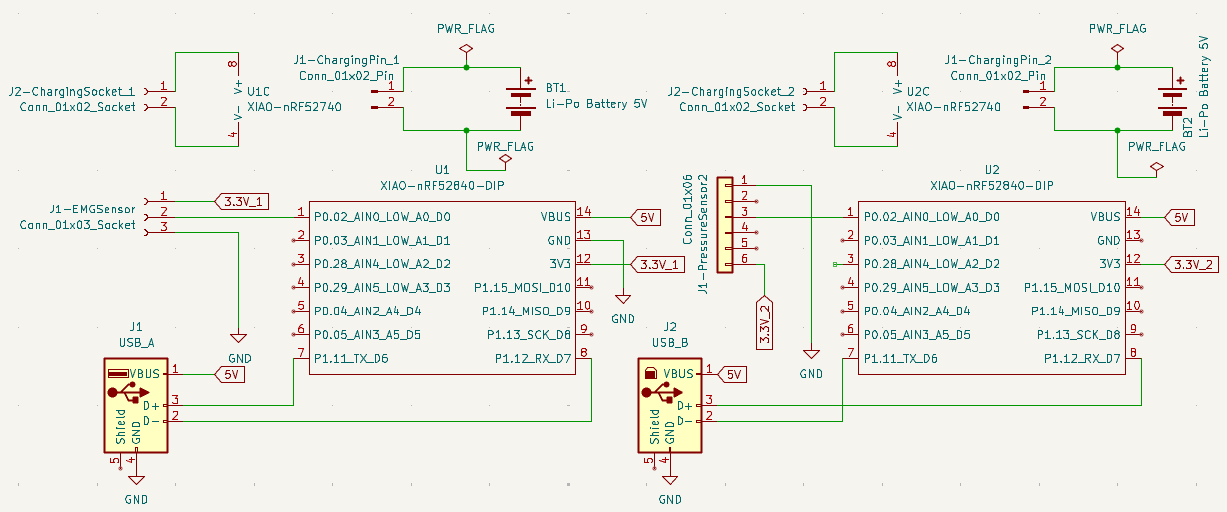
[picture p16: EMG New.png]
  
</p>

The new EMG-LAB sensor has both electrodes embedded directly on the board. To minimize wire length between the sensor and the microcontroller (reducing noise), the board and sensor are placed on the inner forearm. Since tremor must still be measured at the wrist, the original single device was split into two independent units: one on the wrist and one on the inner forearm.

| Aspect | Old Design | Current Design |
|---|---|---|
| EMG sensor | Muscle Sensor V3.0 | EMG-LAB (3.3V, on-board electrodes) |
| Power supply | 2× 9V batteries (90g) | 2× Li-Po 5V (10g each) |
| Analog filtering | Band-stop + low-pass RC circuits | Removed — fully digital |
| Physical form | Single unit on wrist | Two units: forearm (EMG) + wrist (IMU/Pressure) |
| Weight (forearm) | — | 21 g (27 g with battery) |
| Weight (wrist) | — | 16 g (35 g with battery) |
| IMU placement | Wrist | Wrist (enables future forearm tremor localization) |

The two boards each have their own 5 V Li-Po battery on a 2-pin JST connector, so every unit operates fully independently, both operationally and energetically. Dedicated slide switches allow each device to be turned on independently and shut down in a controlled manner.

PCBs were designed for both devices according to the tested prototypes, but due to the limited budget and capabilities of the university equipment, PCB fabrication was abandoned in favor of perfboard prototypes trimmed to fit the components.

Image of the forearm device
<p align="center">
  
  &nbsp;
  
</p>

Image of the wrist device and the general view of the system
<p align="center">
  
  &nbsp;
  
</p>

---

## Device Specifications

### Forearm Unit
- **Weight:** 21 g (27 g including battery)
- **Dimensions:** 3.0 × 4.6 × 2.2 cm
- **Mounting:** Silver chloride gel electrodes adhered directly to the inner forearm skin
- **Battery:** 300 mAh Li-Po, 3.7–5 V, rechargeable via JST connector

### Wrist Unit
- **Weight:** 16 g (35 g including battery)
- **Dimensions:** 2.7 × 5.8 × 1.4 cm
- **Mounting:** Sports fabric strap on the outer wrist
- **Battery:** 300 mAh Li-Po, 3.7–5 V, rechargeable via JST connector

> For reference, a single 9 V battery weighs 45 g — illustrating the significant weight reduction achieved by moving to compact Li-Po cells.

---

## Component List

| Component | Model / Type | Role |
|---|---|---|
| Main board ×2 | NRF52840 (NRF52 family) | Core controller, BLE, IMU |
| IMU | LSM6DS3 (on-board, 3-axis accel + gyro) | Motion and tremor sensing |
| Pressure sensor | ABP-DRRV060MGAA5 | Grip force measurement |
| EMG sensor | EMG-LAB (lab-sourced) | Muscle activation measurement |
| Forearm connector | USB-B (4-pin) | UART inter-device link |
| Wrist connector | USB-A (4-pin) | UART inter-device link |
| Batteries ×2 | 3.7–5 V Li-Po, 300 mAh | Board power supply |
| Electrode pads | Silver chloride gel | EMG signal acquisition |

---

## Future Hardware Work

- **Enclosure:** 3D-printed or workshop-fabricated housing to protect components and prevent patient contact with circuit elements. The current case uses rigid substrates plus a soft cover/sports band; fasteners are the weakest point and need a stronger yet removable mechanism (device access for programming is still required).
- **Power switch:** slide switches are present per unit; a unified power scheme is desirable.
- **Unified charging:** Single charging port / switch for both units instead of two separate JST connectors
- **Extended sensor coverage:** Additional IMU unit on the forearm to localize tremor by segment
- **Analog filter revisit:** At a later stage, when minimizing acquisition latency becomes critical, a minimal analog pre-filter stage may be reintroduced
- **EMG sensor clip:** the borrowed EMG-LAB mounting clip has loosened with wear and needs a proper replacement

---

## Authors

This project was developed as part of a university course project.

- **Iaroslav Petrishchev** — Hardware design, electrical schematics, component selection and procurement, device assembly and testing, case design *(this repository)*
- **Naya Nasr** [LinkedIn](https://www.linkedin.com/in/nasrnaya/)  — NRF52 sensor programming, data acquisition firmware, web application, machine learning pipeline
- **Lucía Pérez Sáez** [LinkedIn]( https://www.linkedin.com/in/lucia-perez-saez/)  — Exercise protocols, signal processing design, backend integration, FSM and WebSocket logic

---

## License

To be determined.

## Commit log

2026-03-17 Revise UART and BLE connection diagram in README
    Updated the diagram in README.md to reflect UART and BLE connections more clearly.
2026-09-19 Enhance README with PCB and case design details
    Clarified PCB fabrication details and added case design specifications. Updated future hardware work section with improved fastening mechanisms and unified charging.
2026-09-19 Update README to reflect design changes and filtering issues
    Removed old single-unit schematic reference and clarified analog filtering issues.
2026-09-19 Refactor README.md section headers and content
    Updated section headers for sensors and design evolution in README.md. Added detailed explanations for embedded firmware and current design improvements.
2026-09-19 Add sensors section to README
    Added a new section for sensors in the README.
